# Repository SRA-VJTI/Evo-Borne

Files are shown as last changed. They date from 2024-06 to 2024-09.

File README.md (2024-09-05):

# Evoborne
This repository focuses on building an open-source _morphobot_
Autonomous human-friendly Multi-Terrain Scaling Vehicle

## Table of Contents
- Introduction
- Features
- Use Case

## Introduction
EvoBorne is a versatile multi-terrain modular robot designed to adapt to various surface and aerial environments, morphing its structure to meet the demands of its surroundings. It operates as a wheeled robot on land, navigating diverse terrains with speed and agility, and seamlessly transforms into a drone when flight is required. Equipped with advanced mapping techniques and a dynamic morphing capability, EvoBorne can autonomously switch between ground and aerial modes, optimizing performance for complex tasks such as search and rescue, environmental monitoring, and exploration. Its robust, customizable design makes it a powerful tool for overcoming challenging environments.

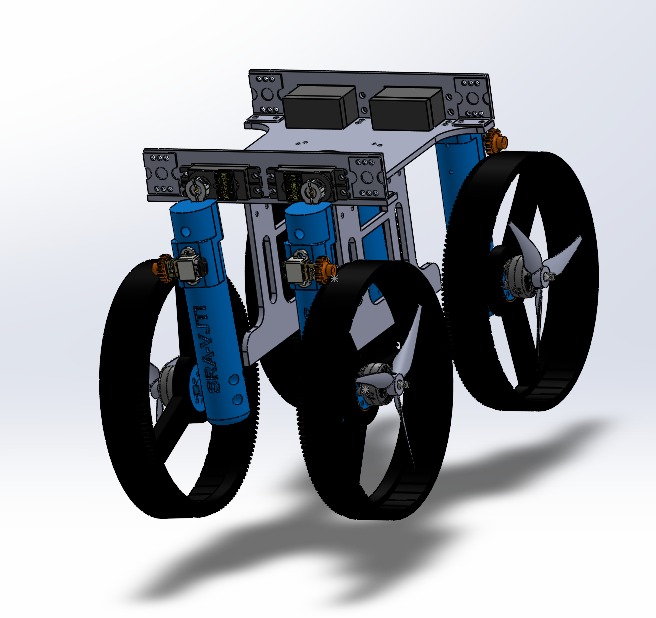
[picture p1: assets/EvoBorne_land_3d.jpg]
EvoBorne chassis


## Features
### Modular & Adaptive Design

EvoBorne's modular design allows it to easily adapt its structure for different environments and tasks. The design is such that it can be reconfigured, enhancing its versatility and enabling quick transitions between ground and aerial modes.

### Powerful Processing Capabilities

EvoBorne is equipped with powerful processors such as the Jetson Nano that can handle real-time navigation. These capabilities allow the robot to execute complex tasks efficiently, supporting advanced terrain mapping and path-finding operations.

### Multiple Operational Modes

EvoBorne can seamlessly switch between multiple operational modes, functioning as a wheeled robot on land and transforming into a drone when aerial mobility is needed. This flexibility allows it to tackle a variety of tasks in diverse environments.

### Efficient Actuation with Custom ESP32 based custom PCB

The robot's actuation system is controlled by a custom ESP32-based development board, providing efficient and precise control over movement and transformations. This tailored setup enhances responsiveness and overall performance.

### Robust & Precise Flight Control

EvoBorne uses a SpeedyBee flight controller for robust and precise flight control, ensuring stable and reliable aerial operations. This system provides advanced control algorithms that enhance the robot's agility and accuracy during flight.

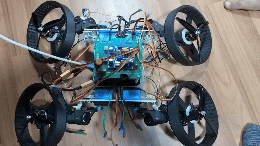
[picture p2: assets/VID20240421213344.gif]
morphing


## Use Case
- EvoBorne is designed to enhance **search and rescue operations** by navigating difficult environments autonomously, using advanced technology to interact with people, and ultimately improving emergency response efficiency. By addressing these issues, EvoBorne could play a vital role in saving lives.
- EvoBorne represents a significant advancement in emergency response technology. Its innovative design and cutting-edge features aim to improve how we handle crises, enabling faster and more efficient assistance in difficult conditions. By reducing the time required to locate and help individuals in danger, EvoBorne could be pivotal in saving lives. Its flexibility and technological sophistication not only make it a valuable tool for rescuers but also push the boundaries of what robots can achieve in real-world scenarios.

## Frameworks & Technologies
- ESP-IDF
- Betaflight
- SolidWorks
- ROS

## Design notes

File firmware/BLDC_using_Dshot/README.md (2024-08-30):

| Supported Targets | ESP32 | ESP32-C3 | ESP32-C6 | ESP32-H2 | ESP32-S2 | ESP32-S3 |
| --- | ----- | --- | --- | --- | --- | --- |
# RMT Infinite Loop Transmit Example -- Dshot ESC (Electronic Speed Controller)

(See the README.md file in the upper level 'examples' directory for more information about examples.)

RMT TX channel can transmit symbols in an infinite loop, where the loop is totally controlled by the hardware. This feature is useful for scenarios where a device needs continuous stimulus.

The [DShot](https://github.com/betaflight/betaflight/wiki/Dshot) is a digital protocol between flight controller (FC) and ESC, which is more resistant to electrical noise than traditional analog protocols. The DShot protocol requires the FC to encode throttle information into pulses with various durations and send out the pulses periodically. This is what an RMT TX channel can perfectly do.

## How to Use Example

### Hardware Required

* A development board with any supported Espressif SOC chip (see `Supported Targets` table above)
* A USB cable for Power supply and programming
* An ESC that supports DShot protocol (this example will take the **DShot300** as an example)

Connection :

```
   BLDC           DShot ESC        12V GND
+--------+     +---------------+    |   |           ESP
|        |     |               |    |   | +----------------------+
|      U +-----+ U          P+ +----+   | |                      |
|        |     |               |        | |                      |
|      V +-----+ V          P- +--------+ |                      |
|        |     |               |          |                      |
|      W +-----+ W         SIG +----------+ DSHOT_ESC_GPIO_NUM   |
|        |     |           GND +----------+ GND                  |
+--------+     +---------------+          +----------------------+
```

The GPIO number used in this example can be changed according to your board, by the macro `DSHOT_ESC_GPIO_NUM` defined in the [source file](main/dshot_esc_example_main.c).

### Build and Flash

Run `idf.py -p PORT flash monitor` to build, flash and monitor the project.

(To exit the serial monitor, type ``Ctrl-]``.)

## Console Output

```
I (0) cpu_start: Starting scheduler on APP CPU.
I (182) example: Create RMT TX channel
I (182) gpio: GPIO[43]| InputEn: 0| OutputEn: 1| OpenDrain: 0| Pullup: 1| Pulldown: 0| Intr:0
I (182) example: Install Dshot ESC encoder
I (182) example: Start RMT TX channel
I (182) example: Start ESC by sending zero throttle for a while...
I (3182) example: Set throttle to 1000, no telemetry
```

The BLDC motor will beep when the ESC receives a burst of initialization pulses. And then starts high-speed rotation at the throttle set in the code.

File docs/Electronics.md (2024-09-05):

---
title: Electronics

---

# Electronics

 - Electronics is a critical part of the EvoBorne robot. All the processing & control applications for the morphobot are performed with the electronics. The electronics for the morphobot has two major components : 
    1. Power Circuitry
    2. Controlling System

## Components used

### **SRA Development Board**
- The [SRA board](https://github.com/SRA-VJTI/sra-board-hardware-design) is our in-house development board based on the ESP32 microcontroller, featuring on-board peripherals such as programmable LEDs, switches, sensor ports for Line Sensor Array and MPU-6050, an over-current and reverse voltage protection circuit, and motor drivers. 
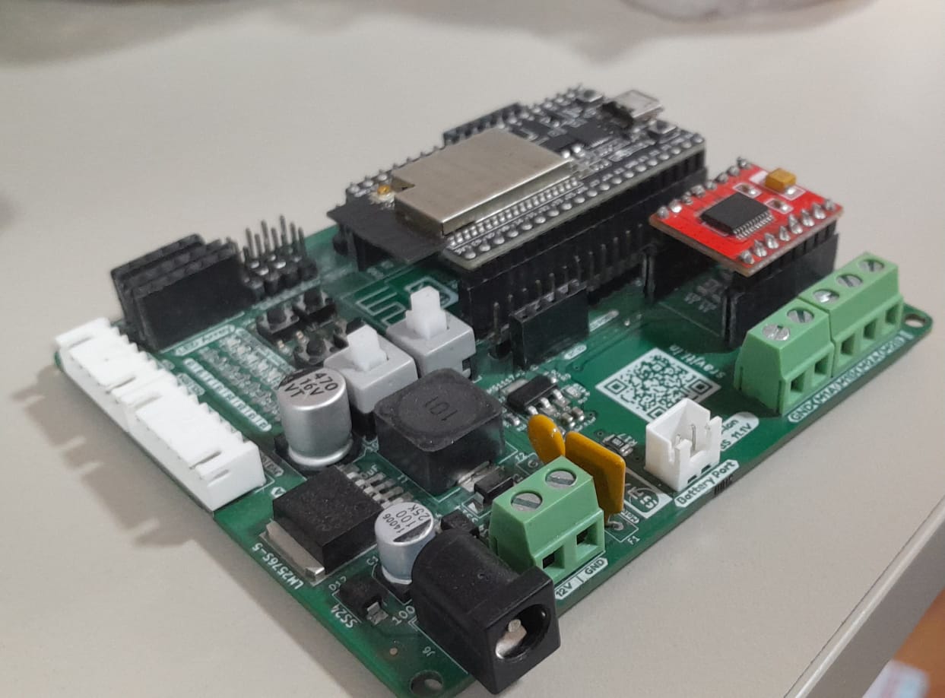
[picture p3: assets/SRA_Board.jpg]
sra-board-24-image
- ![SRA Board v2.5](

- The SRA board is used to connect to & control the servos and the N20 motors through the ESP32. The board has dedicated ports to connect servos as well as normal DC motors. 

### **ESP32-WROOM-32E MCU**
- The ESP32 is primarily being used for controlling the servos and the N20 DC motors for morphing/unmorphing the robot from a wheeled vehicle into a drone. 

### SpeedyBee F405 V3 flight controller
- A flight controller is necessary for controlling the drone effectively. The SpeedyBee F405 V3 has a STM32F405 MCU with an ARM-Cortex M4 core 
- The flight controller’s compact size of 30x30mm makes it compatible with a wide range of frames, from smaller micro quadcopters to larger racing drones. It is based on the popular STM32F405 MCU (Microcontroller Unit) with an ARM Cortex-M4 core, ensuring smooth and efficient processing of data. 
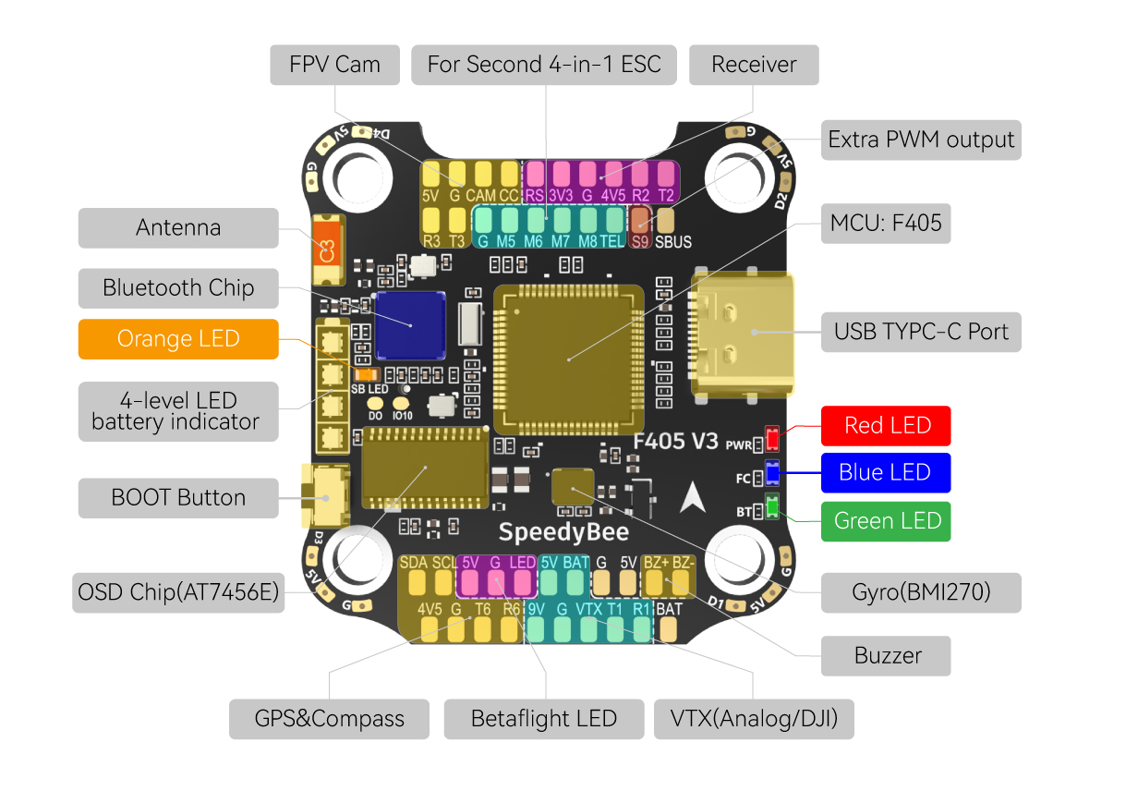
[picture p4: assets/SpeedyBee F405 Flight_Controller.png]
Screenshot from 2024-04-24 10-28-56
 

### Power Circuitry
- The morphobot uses a 24V, 1400 mAh battery to power all of its electronics. Since each component has unique power requirements, an additional circuit is used to manage the input voltage to each component.
- The voltage drop is controlled as required using Buck Converters
- 

### Realsense D435i depth camera
- The Realsense depth camera, specifically the Intel Realsense D435i model, is a stereo vision camera system designed to capture high-resolution depth images. This capability is critical for applications requiring 3D spatial recognition and depth estimation.
- For the morphobot, the Realsense camera provides essential depth information that helps in environment mapping. It allows the morphobot to perceive its surroundings in three dimensions, which is crucial for the drone mode, where understanding the altitude and clearance around obstacles directly influences flight safety and stability.
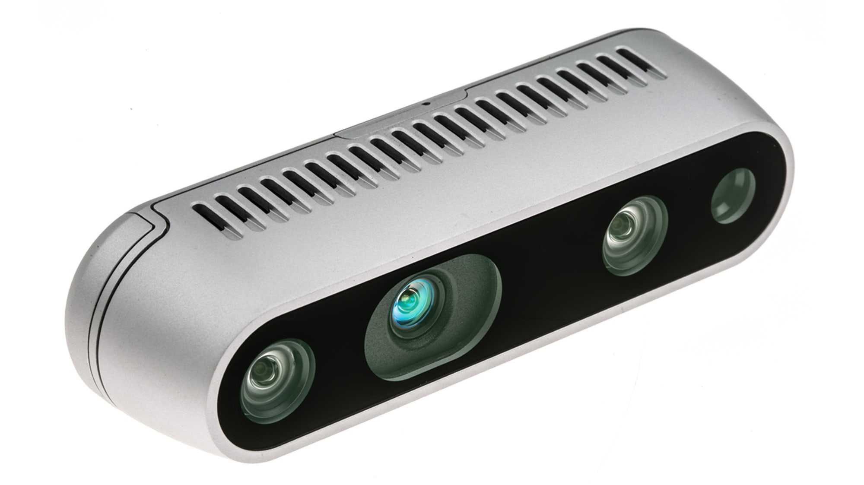
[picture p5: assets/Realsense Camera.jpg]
realsense d435i img
 

- The camera features a wide field of view and can generate depth data at a high frame rate, which is beneficial for the dynamic environments in which the morphobot operates. The integration of this camera enhances the morphobot's ability to interact intelligently with its environment, contributing significantly to its autonomous capabilities.

### Jetson Nano Developer Kit
- The Jetson Nano Developer Kit from NVIDIA is a small, powerful computer designed specifically for learning and development of robotics projects. It is based on the NVIDIA Jetson Nano SoC, which combines a quad-core ARM Cortex-A57 MPCore processor and a 128-core Maxwell GPU. This combination makes it highly effective for tasks,such as image processing & deep learning.
    
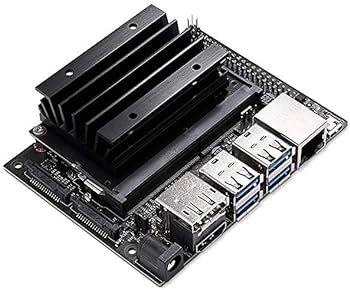
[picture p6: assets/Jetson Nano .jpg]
jetson_nano


- In the context of the morphobot, the Jetson Nano Developer Kit is utilized for high-level processing tasks such as image and video analysis, obstacle detection, and navigation intelligence. Its powerful processing capabilities enable the morphobot to perform complex computations required for autonomous decision-making and environment interaction, particularly in scenarios where rapid response to sensor inputs is crucial.

### 4-in-1 ESC
- Electronic Speed Controllers (ESC's) are integral to controlling the power supplied to the motors of drones. A 4-in-1 ESC consolidates four individual ESCs into one compact module, which simplifies the wiring and reduces the overall weight and complexity of the drone assembly in the morphobot.
- Each of the integrated ESCs can independently manage one of the drone's brushless BLDC motors, providing precise control over the speed and direction of each motor which is crucial for maintaining stability and maneuverability during the drone's flight.
4-in1 esc kit

    The use of a 4-in-1 ESC not only optimizes the electrical efficiency but also improves the reliability and responsiveness of the drone system, which are vital characteristics during both flight and morphing transitions.

Overall, the morphobot's electronics system is a coordinated assembly of different components that work together to deliver impressive capabilities in both its drone and wheeled configurations. From power management and motor control to high-level  depth perception, each component plays an important role in ensuring the morphobot's functionality and performance across various operational scenarios.

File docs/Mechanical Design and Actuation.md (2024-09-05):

---
title: Mechanical Design and Actuation

---

# Mechanical Design and Actuation

Mechanical design is an essential stage in the development of any robot. The robot's future prospects are influenced by how it is designed. 

##  Mechanical Design

__Modular Design__: The EvoBorne's chassis is built of lightweight yet robust components like aluminium and 3D printed PLA parts. The EvoBorne's mainframe is made of aluminium that houses the electronics assembly. The arms and wheels are 3D printed and attached through the servos mounted on the mainframe. 

This modular design facilitates part replacement and maintenance, as well as adaptability to varied configurations for specialized applications or situations.

__Frame and Structure:__

Designing the morphobot was a major task ; as it was to be tailor-made to perform in multiple modes ( aerial & terrestrial ). It was designed keeping in mind the following factors :
1. Terrestrial motion : When traversing on land , the EvoBorne needs to be stable enough to continue smooth motion at moderate velocity on diverse terrain. That meant ensuring the chassis was perfectly balanced in terms of size & weight . Also ,the morphing process was also to be considered;it should be able to morph & unmorph efficiently without any damage to itself or the surroundings. The wheels needed to be large enough to encase the propellers but small enough to maintain a stable COM. 
morphobot_quad_mode

2. Flight : Flying the EvoBorne was the most critical point while designing the EvoBorne . Even a slight discrepancy in the geometry could affect its flying capabilities fatally. The thrust-to-weight ratio was also taken into consideration while designing the frame. It has a H-airframe 
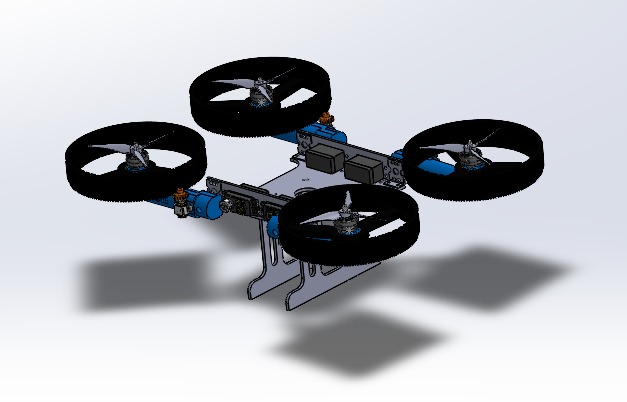
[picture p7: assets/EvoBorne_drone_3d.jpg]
morphobot_drone_mode


### Actuation

Wheel and Drone Components:

Wheels and Motors: For ground mobility, the morphobot is equipped with small, powerful brushless DC motors, possibly the N20 motor type, known for their compact size and high torque output. The wheels are designed to be lightweight with a durable tread capable of handling different terrains.
    Propellers and ESCs: In drone mode, the propellers are deployed. These are driven by brushless motors controlled by 4-in-1 ESCs (Electronic Speed Controllers), which manage the speed and direction of each motor to control flight dynamics such as lift, pitch, roll, and yaw.

Actuation and Transition:

- Servo Motors: 
    - Servo motors are critical for the transformation process, providing precise control over the transition process to switch between the EvoBorne's two forms. They must be robust enough to handle the mechanical stress from the thrust when in drone mode and responsive enough to ensure a smooth transition. 
    - We have used OT5325 servo motors for the EvoBorne that provide a stall torque of 25 kg-cm when operating at 7.4V ; this is essential to ensure that the arms of the EvoBorne do not tilt due to thrust from the propellers. 
- N20 motors:
    - The EvoBorne utilizes these motors to perform terrestrial motion. These motors are connected to the wheel through a spur gear system ; one gear on the shaft and the other on the wheel's circumference. This system is a high-torque,low-speed system that will provide better traction on all surfaces.
- Brushless BLDC motors :
    - The EvoBorne uses Emax ECOII-2807-1700KV BLDC motors for flight . These motors have a 1700 Kv (rpm/volt) rating and are controlled via the 4-in-1 ESC. It uses 6' propellers 

- Locking Mechanisms: Reliable locking mechanisms are essential to ensure stability in both modes. These might include magnetic locks or mechanical latches that secure moving parts once the transformation is complete.

Stability and Maneuverability:

In summary, the mechanical design of the morphobot is a sophisticated blend of robotics engineering, combining elements from both aerial and terrestrial technologies to create a versatile and dynamic machine capable of operating in diverse environments and fulfilling a range of tasks. This design not only challenges existing engineering practices but also pushes the boundaries of what is technically feasible in robotic transformations.

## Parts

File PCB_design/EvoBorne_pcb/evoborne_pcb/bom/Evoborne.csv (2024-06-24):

Reference | Value | Datasheet | Footprint | Qty
C1,C24,C25 | 10uF | ~ | Capacitor_SMD:C_0603_1608Metric | 3
C2,C4,C22,C33 | 0.1uF | ~ | Capacitor_SMD:C_0603_1608Metric | 4
C3 | 22uF | ~ | Capacitor_SMD:C_0603_1608Metric | 1
C5,C9,C12 | 220uF | ~ | Capacitor_SMD:CP_Elec_6.3x7.7 | 3
C6,C7,C8,C10,C13,C14,C15,C17,C18,C26 | 1uF | ~ | Capacitor_SMD:C_0603_1608Metric | 10
C11,C16,C19 | 330uF | ~ | Capacitor_SMD:CP_Elec_8x10.5 | 3
C20,C21 | 22 pF | ~ | Capacitor_SMD:C_0603_1608Metric | 2
D1,D3 | SS34 | http://www.vishay.com/docs/88526/1n5820.pdf | Diode_SMD:D_SMB | 2
D2,D5,D9,D10,D11,D12,D13,D14,D15,D16,D17,D18,D19,D20 | LED | ~ | LED_SMD:LED_0603_1608Metric | 14
D4,D6,D7 | B540 |  | Diode_SMD:Diode B540 | 3
D8 | SS54 | http://www.vishay.com/docs/88526/1n5820.pdf | Diode_SMD:D_SMA | 1
F1 | 3A | ~ | Fuse:RUEF160 | 1
F2 | 5A | ~ | Fuse:5A PTC Fuse RGEF500 | 1
F3 | 300mA | ~ | PTC Fuse:1A PTC Fuse RXEF050 | 1
H1,H2,H3,H4 | MountingHole | ~ | MountingHole:MountingHole_3.2mm_M3 | 4
J1,J2,J3,J4 | B2B-XH-A_LF__SN_ |  | Connector:2 Pin JST | 4
J5,J6,J7,J8 | Conn_01x03_Pin | ~ | Header Pins:Headers 1X03 | 4
J9,J10 | XT60 |  | 2 Male 90 Headers | 2
J11,J12,J15 | Conn_01x08_Male | ~ | Connector_PinHeader_2.54mm:PinHeader_1x08_P2.54mm_Vertical | 3
J13 | Screw_Terminal_01x02 | ~ | TerminalBlock:TerminalBlock_bornier-2_P5.08mm | 1
J14 | USB_C_Receptacle_USB2.0 | https://www.usb.org/sites/default/files/documents/usb_type-c.zip | Connector_USB:USB_C_Receptacle_G-Switch_GT-USB-7010ASV | 1
J16,J17 | Conn_01x14_Pin | ~ | Connector_PinHeader_2.54mm:PinHeader_1x14_P2.54mm_Vertical | 2
J18,J19 | Conn_01x02_Pin | ~ | Connector_PinHeader_2.54mm:PinHeader_1x02_P2.54mm_Vertical | 2
L1,L2,L3 | 47uH | ~ | Inductor_SMD:L_10.4x10.4_H4.8 | 3
Q1,Q2 | SS8050 | https://www.fairchildsemi.com/datasheets/2N/2N3904.pdf | Package_TO_SOT_SMD:SOT-23 | 2
R1,R2,R3,R4 | 1k |  | Resistor_SMD:R_1206_3216Metric | 4
R19 | 1k | ~ | Resistor_SMD:R_0603_1608Metric | 1
R5,R6,R7 | TrimPOT 3296 |  | Potentiometer_THT:TrimPOT_3296 | 3
R8,R9,R27,R11,R12,R13,R14,R15,R16,R17,R18,R20 | 330 | ~ | Resistor_SMD:R_0603_1608Metric | 12
R10 | 100k | ~ | Resistor_SMD:R_0805_2012Metric | 1
R21 | 2k | ~ | Resistor_SMD:R_0603_1608Metric | 1
R22 | 3.3k | ~ | Resistor_SMD:R_0805_2012Metric | 1
R23,R24 | 6.8k | ~ | Resistor_SMD:R_0805_2012Metric | 2
R25,R26,R28,R29 | 5.1 k | ~ | Resistor_SMD:R_0402_1005Metric | 4
SW1 | High Current 3 Pin spdt Switch |  | Switches:3pin High Current SPDT Switch | 1
SW2 | SW_N20 | ~ | Switches:6 Pin THT Push Switch | 1
SW3 | SW_Servos | ~ | Switches:6 Pin THT Push Switch | 1
SW4 | SW_Jetson | ~ | Switches:6 Pin THT Push Switch | 1
SW5 | EN | ~ | Button_Switch_SMD:SW_Push_SPST_NO_Alps_SKRK | 1
SW6 | BOOT | ~ | Button_Switch_SMD:SW_Push_SPST_NO_Alps_SKRK | 1
SW7,SW8 | SW_Push_Dual | ~ | Switches:Tactile Smd 2x2 | 2
U1 | TB6612FNG |  | Motor driver:TB6612FNG | 1
U2 | AMS1117-3.3 | http://www.advanced-monolithic.com/pdf/ds1117.pdf | Package_TO_SOT_SMD:SOT-223-3_TabPin2 | 1
U3 | ESP32-WROOM Chip |  | RF_Module:ESP32-WROOM-32E__4MB_HIGH_TEMP_CHIP | 1
U4,U5,U6 | XL4015 | http://www.xlsemi.net/datasheet/XL4015%20datasheet-English.pdf | Package_TO_SOT_SMD:TO-263-5_TabPin3 | 3
U7 | CH340G | http://www.datasheet5.com/pdf-local-2195953 | Package_SO:SOIC-16_3.9x9.9mm_P1.27mm | 1
Y1 | 12MHz | ~ | Crystal:Crystal_SMD_3225-4Pin_3.2x2.5mm | 1

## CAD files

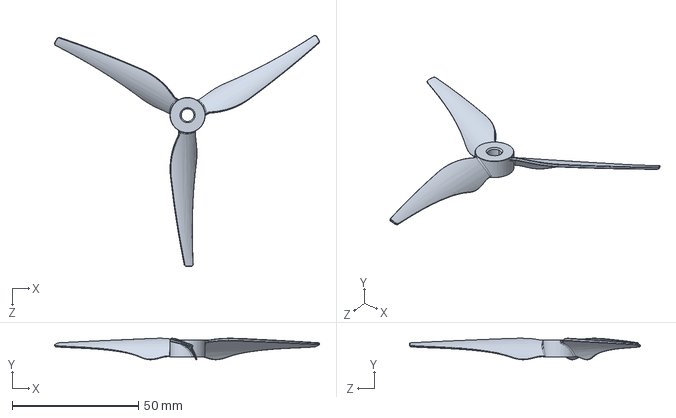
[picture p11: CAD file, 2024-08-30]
CAD_designs/gemfan propeller 51466.SLDPRT
105.0 x 8.54 x 91.6 mm

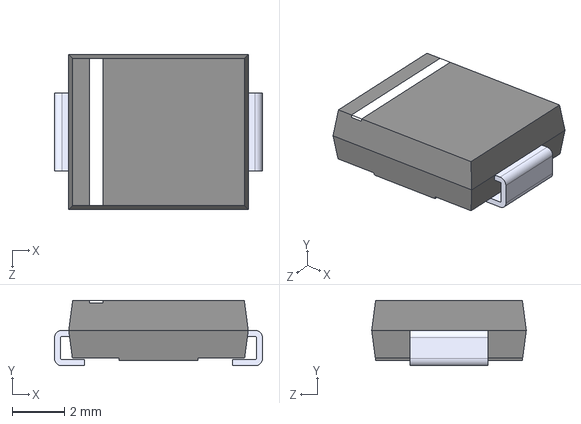
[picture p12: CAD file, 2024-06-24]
PCB_design/EvoBorne_pcb/evoborne_pcb/components_libraries/B540/B540C-13-F.step
7.94 x 2.50 x 5.91 mm

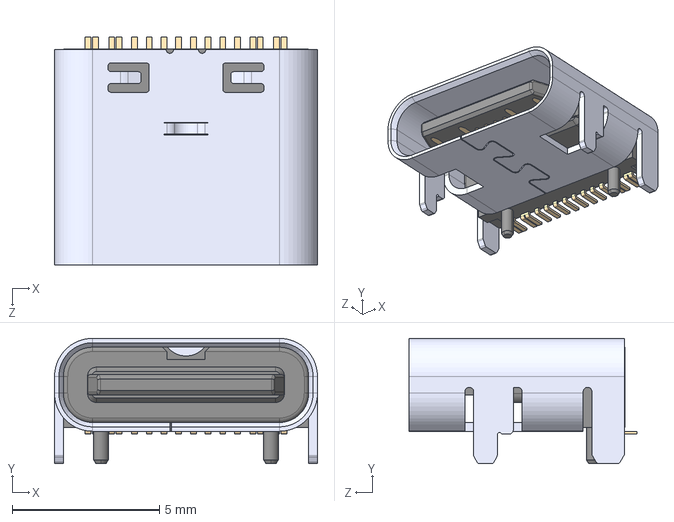
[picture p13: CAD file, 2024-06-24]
PCB_design/EvoBorne_pcb/evoborne_pcb/components_libraries/Connectors/USB C/CSP-USC16-TR.step
8.94 x 4.26 x 7.75 mm

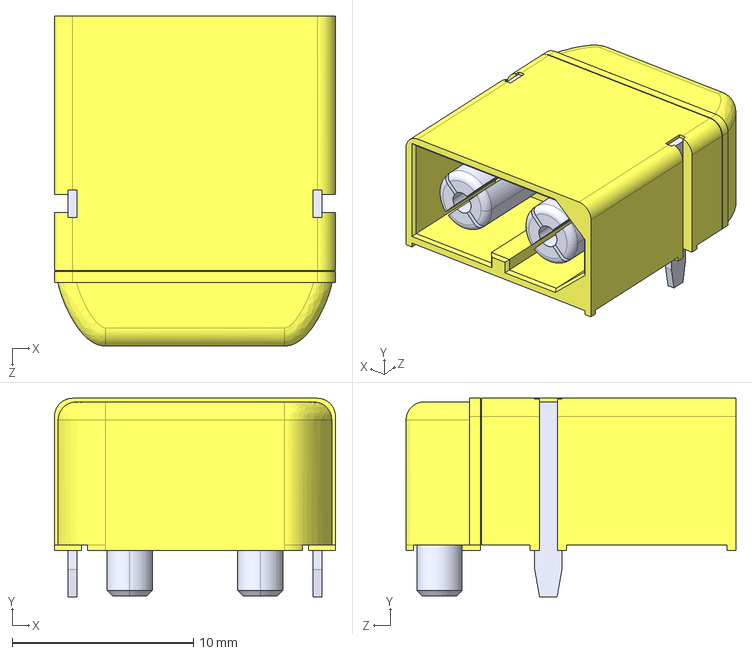
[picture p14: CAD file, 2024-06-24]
PCB_design/EvoBorne_pcb/evoborne_pcb/components_libraries/Connectors/XT 60/XT60PW-M.step
15.5 x 11.0 x 18.2 mm

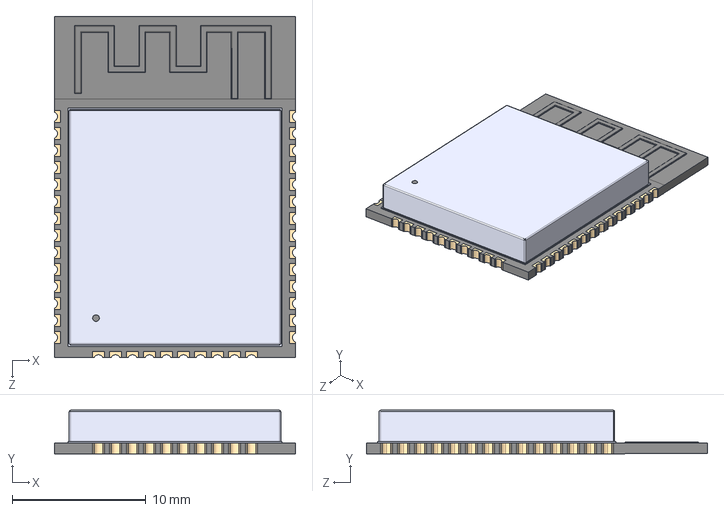
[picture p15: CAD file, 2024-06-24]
PCB_design/EvoBorne_pcb/evoborne_pcb/components_libraries/ESP32-WROOM/ESP32-WROOM-32E__4MB_HIGH_TEMP_.step
18.0 x 3.25 x 25.5 mm

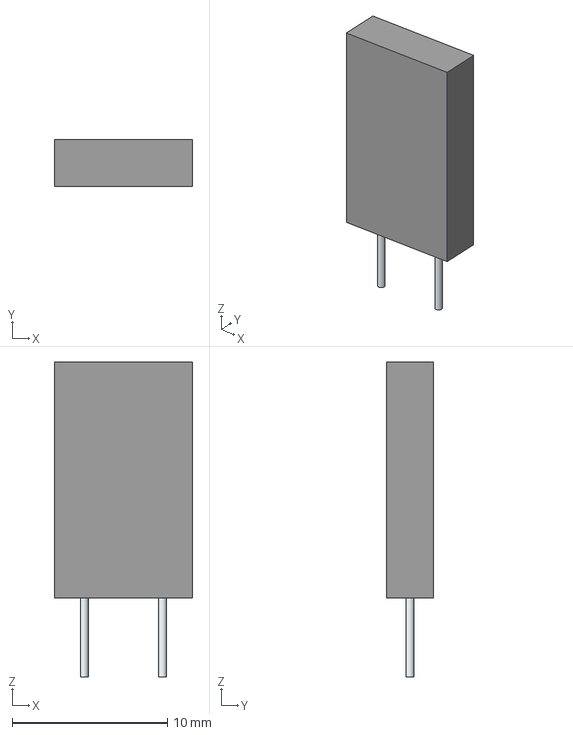
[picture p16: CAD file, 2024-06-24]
PCB_design/EvoBorne_pcb/evoborne_pcb/components_libraries/Fuse/3A PTC Fuse RUEF160/RUEF160.stp
8.90 x 3.00 x 20.3 mm
Leads

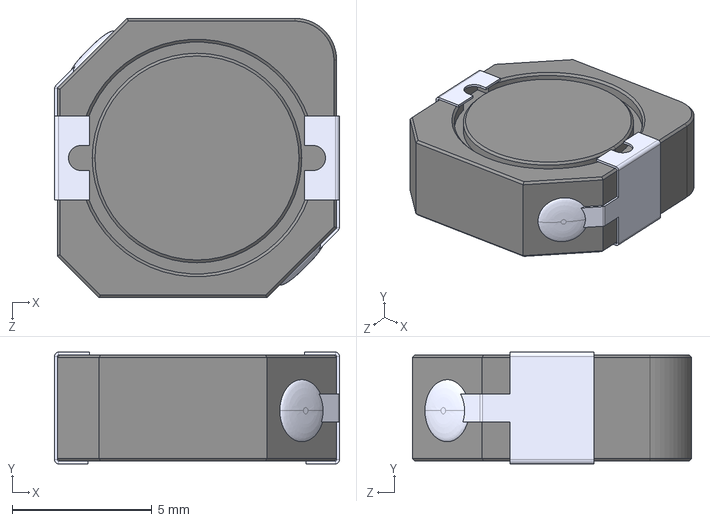
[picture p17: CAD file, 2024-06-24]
PCB_design/EvoBorne_pcb/evoborne_pcb/components_libraries/Inductor/47uH Inductor.STEP
10.2 x 4.00 x 10.0 mm

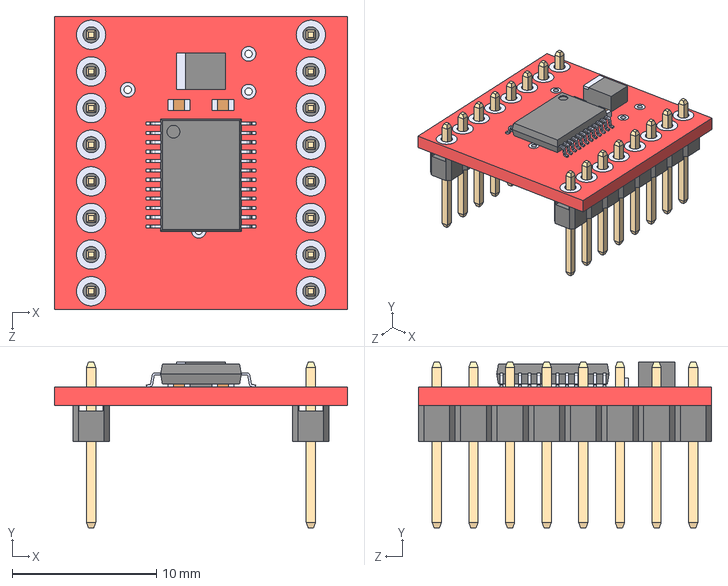
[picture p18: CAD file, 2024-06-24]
PCB_design/EvoBorne_pcb/evoborne_pcb/components_libraries/Motor Driver/ROB-14450.step
20.3 x 11.5 x 20.3 mm

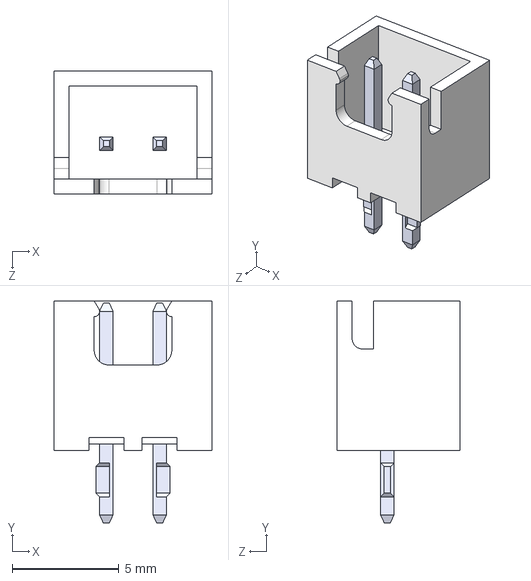
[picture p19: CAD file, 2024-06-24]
PCB_design/EvoBorne_pcb/evoborne_pcb/components_libraries/Motor JST Connector/B2B-XH-A_LF__SN_.step
7.40 x 10.4 x 5.75 mm

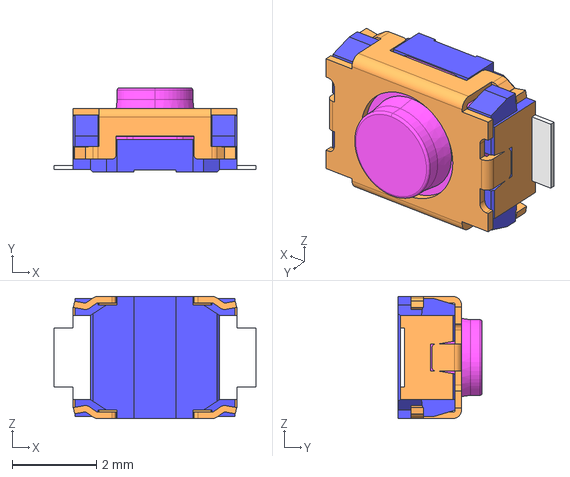
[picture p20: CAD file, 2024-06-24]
PCB_design/EvoBorne_pcb/evoborne_pcb/components_libraries/Switch/Esp-32 Switch/skrkaee010.stp
4.80 x 2.00 x 2.90 mm

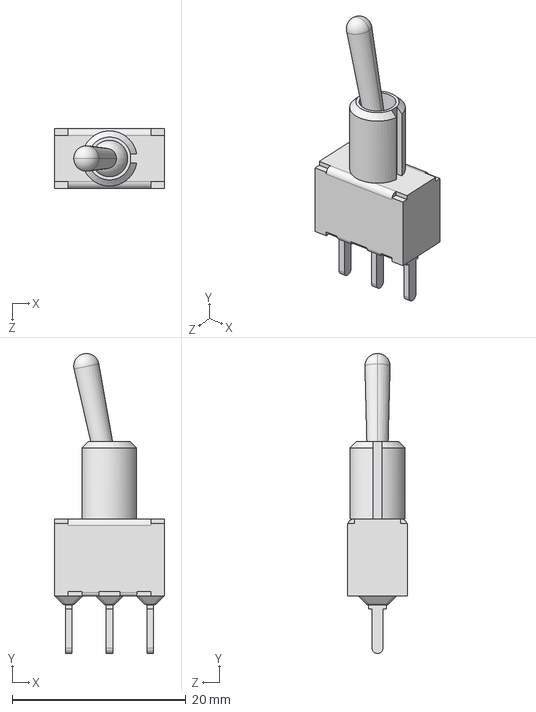
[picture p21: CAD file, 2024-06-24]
PCB_design/EvoBorne_pcb/evoborne_pcb/components_libraries/Switch/High Current 3 Pin spdt Switch/100SP3T1B1M2QEH.step
12.7 x 34.5 x 6.86 mm

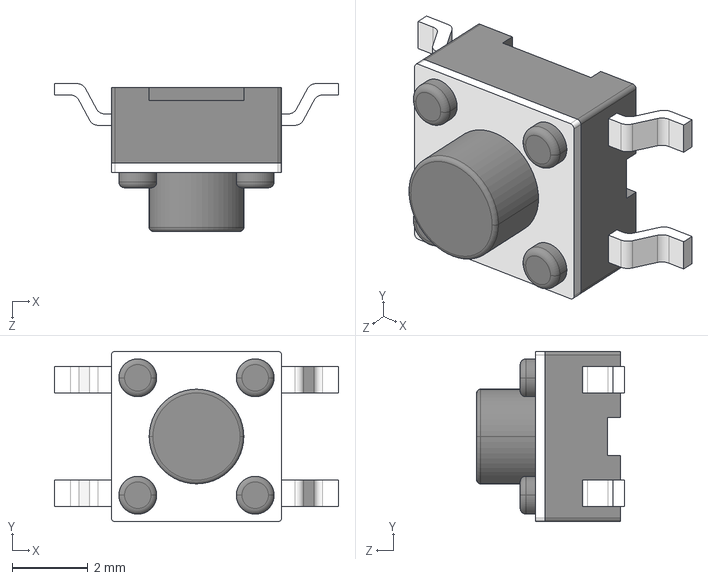
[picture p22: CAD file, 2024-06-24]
PCB_design/EvoBorne_pcb/evoborne_pcb/components_libraries/Switch/tactile_smd/spst_tactile_sw_2x02_smd.stp
7.50 x 4.50 x 3.90 mm

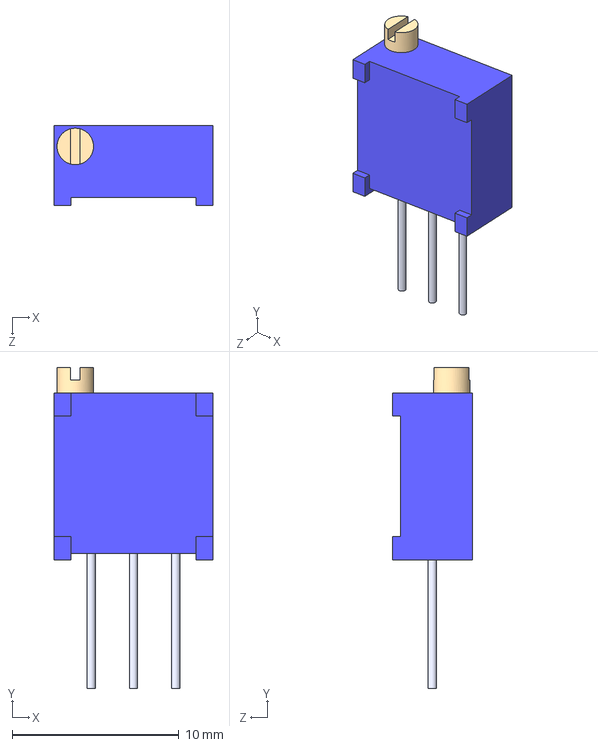
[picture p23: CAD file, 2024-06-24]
PCB_design/EvoBorne_pcb/evoborne_pcb/components_libraries/TrimPOT 3296/3296W-1-250.step
9.53 x 19.3 x 4.83 mm

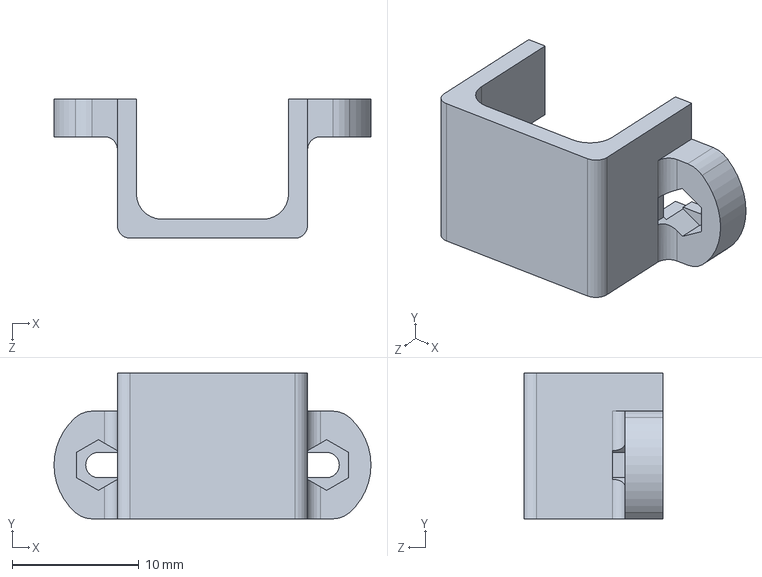
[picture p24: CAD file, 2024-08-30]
CAD_designs/N20-Bracket.SLDPRT
25.0 x 11.5 x 11.0 mm

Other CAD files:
PCB_design/EvoBorne_pcb/evoborne_pcb/components_libraries/Switch/dpdt_tht/dpdt_sw_2x03_tht.STEP
CAD_designs/stand.SLDPRT
CAD_designs/Right_leg_final.SLDPRT
CAD_designs/Bearing_Proto.SLDPRT
CAD_designs/Chassis2.SLDPRT
CAD_designs/Left_leg_final.SLDPRT
CAD_designs/Mg995.SLDPRT
CAD_designs/Motor_HOLDER2.O.SLDPRT
CAD_designs/N20 DC MOTOR.SLDPRT
CAD_designs/N20-Gear.SLDPRT
CAD_designs/SERVO ARM HORN 25T ALUMINIUM.step.SLDPRT
CAD_designs/Wheel_morpho.SLDPRT
PCB_design/EvoBorne_pcb/evoborne_pcb/components_libraries/Fuse/3A PTC Fuse RUEF160/RUEF160.stl
PCB_design/EvoBorne_pcb/evoborne_pcb/components_libraries/Switch/dpdt_tht/dpdt_sw_2x03_tht - Copy.STEP

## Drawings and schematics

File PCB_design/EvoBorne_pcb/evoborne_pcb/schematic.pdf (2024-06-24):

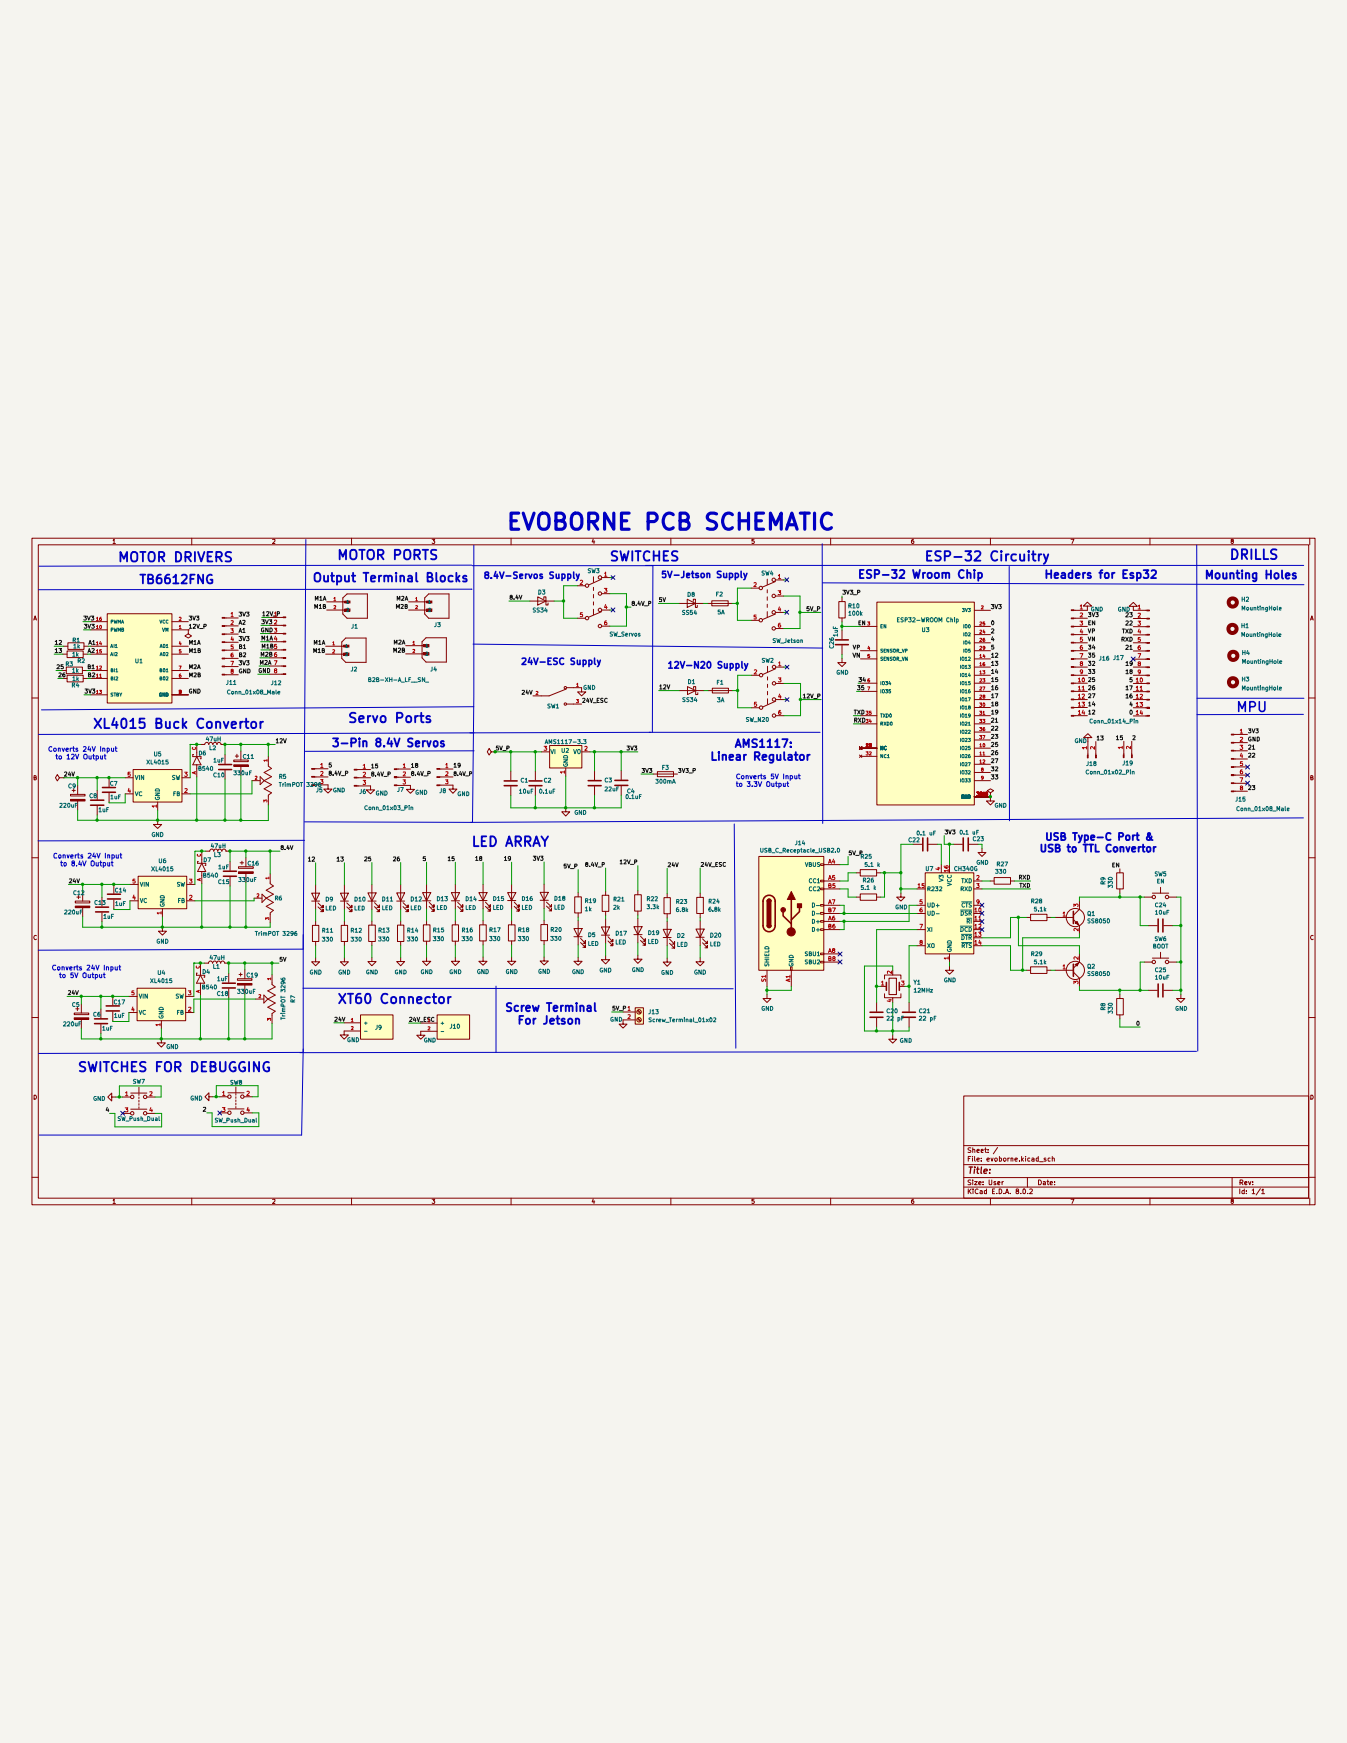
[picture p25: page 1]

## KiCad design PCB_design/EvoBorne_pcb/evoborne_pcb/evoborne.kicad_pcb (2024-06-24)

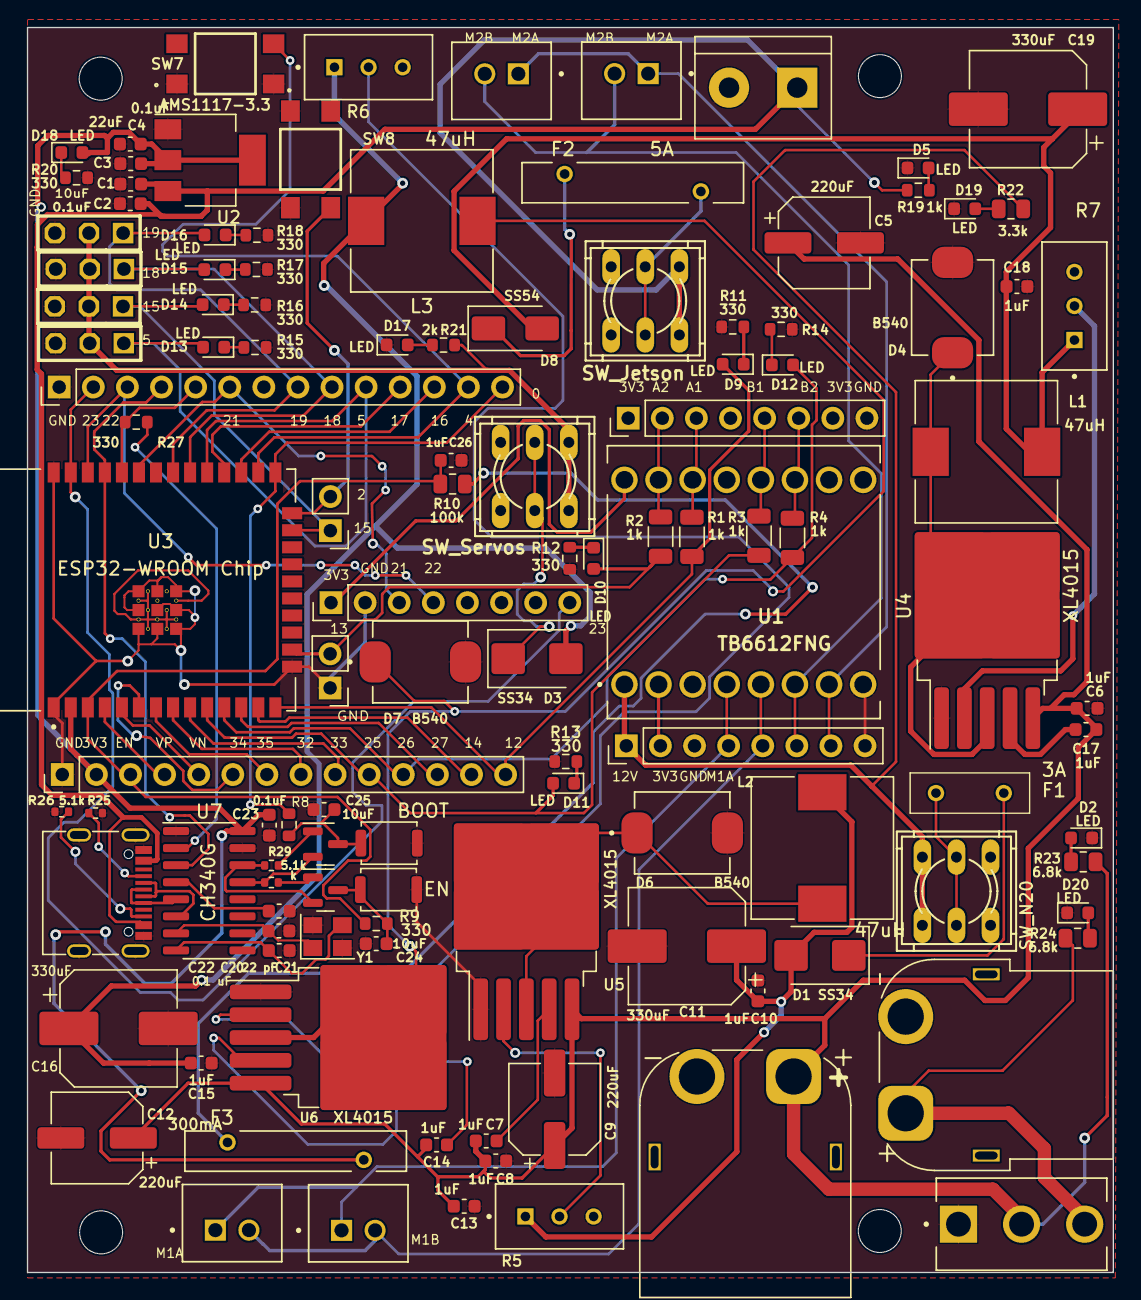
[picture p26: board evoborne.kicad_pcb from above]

Board: 2 copper layers, 80.9 x 92.7 mm, 122 parts (0 on the bottom side), 88 nets.

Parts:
C1, C24, C25: 10uF; C_0603_1608Metric
C2, C4, C23: 0.1uF; C_0603_1608Metric
C3: 22uF; C_0603_1608Metric
C5, C9, C12: 220uF; CP_Elec_6.3x7.7
C6, C7, C8, C10, C13, C14, C15, C17, C18, C26: 1uF; C_0603_1608Metric
C11, C16, C19: 330uF; CP_Elec_8x10.5
C20, C21: 22 pF; C_0603_1608Metric
C22: 0.1 uF; C_0603_1608Metric
D1, D3: SS34; D_SMB
D2, D5, D9, D10, D11, D12, D13, D14, D15, D16, D17, D18, D19, D20: LED; LED_0603_1608Metric
D4, D6, D7: B540; Diode B540
D8: SS54; D_SMA
F1: 3A; RUEF160
F2: 5A; 5A PTC Fuse RGEF500
F3: 300mA; 1A PTC Fuse RXEF050
H1, H2, H3, H4: MountingHole; MountingHole_3.2mm_M3
J1, J2, J3, J4: B2B-XH-A_LF__SN_; 2 Pin JST
J5, J6, J7, J8: Conn_01x03_Pin; Headers 1X03
J9: XT60; AMASS_XT60PW-M_1x02_P7.20mm_Horizontal
J10: XT60; AMASS_XT60PW-F_1x02_P7.20mm_Horizontal
J11, J12, J15: Conn_01x08_Male; PinHeader_1x08_P2.54mm_Vertical
J13: Screw_Terminal_01x02; TerminalBlock_bornier-2_P5.08mm
J14: USB_C_Receptacle_USB2.0; USB_C_Receptacle_G-Switch_GT-USB-7010ASV
J16, J17: Conn_01x14_Pin; PinHeader_1x14_P2.54mm_Vertical
J18, J19: Conn_01x02_Pin; PinHeader_1x02_P2.54mm_Vertical
L1, L2, L3: 47uH; L_10.4x10.4_H4.8
Q1, Q2: SS8050; SOT-23
R1, R2, R3, R4: 1k; R_1206_3216Metric
R5, R6, R7: TrimPOT 3296; TrimPOT_3296
R8, R9, R11, R12, R13, R14, R15, R16, R17, R18, R20, R27: 330; R_0603_1608Metric
R10: 100k; R_0805_2012Metric
R19: 1k; R_0603_1608Metric
R21: 2k; R_0603_1608Metric
R22: 3.3k; R_0805_2012Metric
R23, R24: 6.8k; R_0805_2012Metric
R25: 5.1 k; R_0402_1005Metric
R26, R28, R29: 5.1k; R_0402_1005Metric
SW1: High Current 3 Pin spdt Switch; 3pin High Current SPDT Switch
SW2: SW_N20; 6 Pin THT Push Switch
SW3: SW_Servos; 6 Pin THT Push Switch
SW4: SW_Jetson; 6 Pin THT Push Switch
SW5: EN; SW_Push_SPST_NO_Alps_SKRK
SW6: BOOT; SW_Push_SPST_NO_Alps_SKRK
SW7, SW8: SW_Push_Dual; Tactile Smd 2x2
U1: TB6612FNG
U2: AMS1117-3.3; SOT-223-3_TabPin2
U3: ESP32-WROOM Chip; ESP32-WROOM-32E__4MB_HIGH_TEMP_CHIP
U4, U5, U6: XL4015; TO-263-5_TabPin3
U7: CH340G; SOIC-16_3.9x9.9mm_P1.27mm
Y1: 12MHz; Crystal_SMD_3225-4Pin_3.2x2.5mm

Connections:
/0: J17.14, R8.2, U3.25 (IO0)
/2: J19.2, SW8.4, U3.24 (IO2)
/3V3: C3.1, C4.1, C23.2, D18.2 (A), F3.1, J11.1, J11.4, J11.7, J12.2, J15.1, J16.2, U1.2 (VCC), U1.10 (PWMB), U1.13 (STBY), U1.16 (PWMA), U2.2 (VO), U3.2 (3V3), U7.16 (VCC)
/3V3_P: F3.2, R10.2
/4: J17.13, SW7.4, U3.26 (IO4)
/5: D13.2 (A), J5.1, J17.10, U3.29 (IO5)
/5V: C18.1, C19.1, D8.2 (A), L1.2, R7.1
/5V_P: C1.1, C2.1, J13.1, J14.A4 (VBUS), J14.A9 (VBUS), J14.B4 (VBUS), J14.B9 (VBUS), R19.1, SW4.3 (C), SW4.6 (C), U2.3 (VI)
/8.4V: C15.1, C16.1, D3.2 (A), L3.2, R6.1
/8.4V_P: J5.2, J6.2, J7.2, J8.2, R21.1, SW3.3 (C), SW3.6 (C)
/12: D9.2 (A), J16.14, R1.1, U3.14 (IO12)
/12V: C10.1, C11.1, D1.2 (A), L2.2, R5.1
/12V_P: J12.1, R22.1, SW2.3 (C), SW2.6 (C), U1.1 (VM)
/13: D10.2 (A), J18.2, R2.1, U3.16 (IO13)
/14: J16.13, U3.13 (IO14)
/15: D14.2 (A), J6.1, J19.1, U3.23 (IO15)
/16: J17.12, U3.27 (IO16)
/17: J17.11, U3.28 (IO17)
/18: D15.2 (A), J7.1, J17.9, U3.30 (IO18)
/19: D16.2 (A), J8.1, J17.8, U3.31 (IO19)
/21: J15.3, J17.6, U3.33 (IO21)
/22: J15.4, J17.3, U3.36 (IO22)
/23: J15.8, J17.2, U3.37 (IO23)
/24V: C5.1, C6.1, C7.1, C8.1, C9.1, C12.1, C13.1, C14.1, C17.1, J9.1 (+), R23.1, SW1.2, U4.5 (VIN), U5.5 (VIN), U6.5 (VIN)
/24V_ESC: J10.1 (+), R24.1, SW1.3
/25: D11.2 (A), J16.10, R3.1, U3.10 (IO25)
/26: D12.2 (A), J16.11, R4.1, U3.11 (IO26)
/27: J16.12, U3.12 (IO27)
/32: J16.8, U3.8 (IO32)
/33: J16.9, U3.9 (IO33)
/34: J16.6, U3.6 (IO34)
/35: J16.7, U3.7 (IO35)
/A1: J11.3, R1.2, U1.14 (AI1)
/A2: J11.2, R2.2, U1.15 (AI2)
/B1: J11.5, R3.2, U1.12 (BI1)
/B2: J11.6, R4.2, U1.11 (BI2)
/EN: C26.1, J16.3, R9.1, R10.1, U3.3 (EN)
/M1A: J1.1, J2.1, J12.4, U1.4 (A01)
/M1B: J1.2, J2.2, J12.5, U1.5 (A02)
/M2A: J3.1, J4.1, J12.7, U1.7 (B01)
/M2B: J3.2, J4.2, J12.6, U1.6 (B02)
/RXD: J17.5, R27.1, U3.34 (RXD0)
/TXD: J17.4, U3.35 (TXD0), U7.3 (RXD)
/VN: J16.5, U3.5 (SENSOR_VN)
/VP: J16.4, U3.4 (SENSOR_VP)
GND: C1.2, C2.2, C3.2, C4.2, C5.2, C6.2, C8.2, C9.2, C10.2, C11.2, C12.2, C13.2, C15.2, C16.2, C18.2, C19.2, C20.2, C21.2, C22.2, C23.1, C24.1, C25.1, C26.2, D2.1 (K), D4.A, D5.1 (K), D6.A, D7.A, D17.1 (K), D19.1 (K), D20.1 (K), J5.3, J6.3, J7.3, J8.3, J9.2 (-), J10.2 (-), J11.8, J12.3, J12.8, J13.2, J14.A1 (GND), J14.A12 (GND), J14.B1 (GND), J14.B12 (GND), J14.S1 (SHIELD), J15.2, J16.1, J17.1, J18.1, R5.3, R6.3, R7.3, R11.2, R12.2, R13.2, R14.2, R15.2, R16.2, R17.2, R18.2, R20.2, R25.2, R26.1, SW1.1, SW5.2, SW6.2, SW7.1, SW7.2, SW8.1, SW8.2, U1.3 (GND), U1.8 (GND), U1.9 (GND), U2.1 (GND), U3.1 (GND), U3.15 (GND), U3.38 (GND), U3.39_1 (GND), U3.39_2 (GND), U3.39_3 (GND), U3.39_4 (GND), U3.39_5 (GND), U3.39_6 (GND), U3.39_7 (GND), U3.39_8 (GND), U3.39_9 (GND), U4.1 (GND), U5.1 (GND), U6.1 (GND), U7.1 (GND), U7.15 (R232), Y1.2, Y1.4
unnamed: D1.1 (K), F1.1
unnamed: D2.2 (A), R23.2
unnamed: D3.1 (K), SW3.2 (B), SW3.5 (B)
unnamed: D5.2 (A), R19.2
unnamed: D8.1 (K), F2.1
unnamed: D9.1 (K), R11.1
unnamed: D10.1 (K), R12.1
unnamed: D11.1 (K), R13.1
unnamed: D12.1 (K), R14.1
unnamed: D13.1 (K), R15.1
unnamed: D14.1 (K), R16.1
unnamed: D15.1 (K), R17.1
unnamed: D16.1 (K), R18.1
unnamed: D17.2 (A), R21.2
unnamed: D18.1 (K), R20.1
unnamed: D19.2 (A), R22.2
unnamed: D20.2 (A), R24.2
unnamed: F1.2, SW2.2 (B), SW2.5 (B)
unnamed: F2.2, SW4.2 (B), SW4.5 (B)
unnamed: J14.A5 (CC1), R25.1
unnamed: J14.B5 (CC2), R26.2
unnamed: Q1.1 (B), R28.1
unnamed: C24.2, Q1.3 (C), R9.2, SW5.1
unnamed: Q1.2 (E), R29.2, U7.14 (~RTS)
unnamed: Q2.1 (B), R29.1
unnamed: C25.2, Q2.3 (C), R8.1, SW6.1
unnamed: Q2.2 (E), R28.2, U7.13 (~DTR)
unnamed: R7.2, U4.2 (FB)
unnamed: D4.C, L1.1, U4.3 (SW)
unnamed: C17.2, U4.4 (VC)
unnamed: R5.2, U5.2 (FB)
unnamed: D6.C, L2.1, U5.3 (SW)
unnamed: C7.2, U5.4 (VC)
unnamed: R6.2, U6.2 (FB)
unnamed: D7.C, L3.1, U6.3 (SW)
unnamed: C14.2, U6.4 (VC)
unnamed: R27.2, U7.2 (TXD)
unnamed: J14.A6 (D+), J14.B6 (D+), U7.5 (UD+)
unnamed: J14.A7 (D-), J14.B7 (D-), U7.6 (UD-)
unnamed: C22.1, U7.4 (V3)
unnamed: C20.1, U7.7 (XI), Y1.1
unnamed: C21.1, U7.8 (XO), Y1.3

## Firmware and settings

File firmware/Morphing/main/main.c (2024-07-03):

/*
MIT License

Copyright (c) 2024 Society of Robotics and Automation

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
THE SOFTWARE IS PROVIDED "AS IS", WITHOUT WARRANTY OF ANY KIND, EXPRESS OR
IMPLIED, INCLUDING BUT NOT LIMITED TO THE WARRANTIES OF MERCHANTABILITY,
FITNESS FOR A PARTICULAR PURPOSE AND NONINFRINGEMENT. IN NO EVENT SHALL THE
AUTHORS OR COPYRIGHT HOLDERS BE LIABLE FOR ANY CLAIM, DAMAGES OR OTHER
LIABILITY, WHETHER IN AN ACTION OF CONTRACT, TORT OR OTHERWISE, ARISING FROM,
OUT OF OR IN CONNECTION WITH THE SOFTWARE OR THE USE OR OTHER DEALINGS IN THE
SOFTWARE.
*/
#include "sra_board.h"
#include "tuning_websocket_server.h"

#define TAG "MORPHING"
#define DRONE_MODE 1
#define QUAD_MODE 0
#define SET_SERVO_90 83
#define MIN_PWM (40.0f) 
#define MAX_PWM (80.0f)

motor_handle_t motor1;
motor_handle_t motor2;
bool MORPH_UNLOCK = 1, MORPH_ACTIVATE, MORPHED, DEMORPHED, FLIGHT_READY;
servo_config servo_a = {
	.servo_pin = SERVO_A,
	.min_pulse_width = CONFIG_SERVO_A_MIN_PULSEWIDTH,
	.max_pulse_width = CONFIG_SERVO_A_MAX_PULSEWIDTH,
	.max_degree = CONFIG_SERVO_A_MAX_DEGREE,
};

servo_config servo_b = {
	.servo_pin = SERVO_B,
	.min_pulse_width = CONFIG_SERVO_B_MIN_PULSEWIDTH,
	.max_pulse_width = CONFIG_SERVO_B_MAX_PULSEWIDTH,
	.max_degree = CONFIG_SERVO_B_MAX_DEGREE,
};

servo_config servo_c = {
	.servo_pin = SERVO_C,
	.min_pulse_width = CONFIG_SERVO_C_MIN_PULSEWIDTH,
	.max_pulse_width = CONFIG_SERVO_C_MAX_PULSEWIDTH,
	.max_degree = CONFIG_SERVO_C_MAX_DEGREE,
};

servo_config servo_d = {
	.servo_pin = SERVO_D,
	.min_pulse_width = CONFIG_SERVO_D_MIN_PULSEWIDTH,
	.max_pulse_width = CONFIG_SERVO_D_MAX_PULSEWIDTH,
	.max_degree = CONFIG_SERVO_D_MAX_DEGREE,
};

static void mcpwm_servo_control(void *arg)
{
	ESP_ERROR_CHECK(enable_motor_driver(&motor1, MOTOR_A_0));
	ESP_ERROR_CHECK(enable_motor_driver(&motor2, MOTOR_A_1));
	ESP_ERROR_CHECK(enable_servo());
	
	while (1)
	{
		if (MORPH_UNLOCK == QUAD_MODE){
			if (DEMORPHED == false){
				ESP_LOGI(TAG, "Demorphing...\n");
				for (int i = 0; i <= SET_SERVO_90; i+=2){
					ESP_ERROR_CHECK(set_angle_servo(&servo_a, i));
					ESP_ERROR_CHECK(set_angle_servo(&servo_b, SET_SERVO_90 - i));
					ESP_ERROR_CHECK(set_angle_servo(&servo_c, i));
					ESP_ERROR_CHECK(set_angle_servo(&servo_d, SET_SERVO_90 - i));
					vTaskDelay(10);
				}
				DEMORPHED = true;
				ESP_LOGI(TAG, "QUAD MODE ACTIVATED\n");
				ESP_LOGI(TAG, "Activating wheels...\n");
			}
			else {
				if(read_comms().val_changed){
            		float speed = read_comms().speed;
            		ESP_LOGI(TAG, "speed: %f", speed);                                          //print to console
            		float motor_pwm = bound((speed), MIN_PWM, MAX_PWM);
            		if(read_comms().front){
						ESP_LOGI(TAG, "forward");
						ESP_ERROR_CHECK(set_motor_speed(motor1, MOTOR_FORWARD, motor_pwm));
						ESP_ERROR_CHECK(set_motor_speed(motor2, MOTOR_FORWARD, motor_pwm));
					} else if(read_comms().back){
						ESP_LOGI(TAG, "backward");
						ESP_ERROR_CHECK(set_motor_speed(motor1, MOTOR_BACKWARD, motor_pwm));
						ESP_ERROR_CHECK(set_motor_speed(motor2, MOTOR_BACKWARD, motor_pwm));
					} else if(read_comms().right_turn) {
						ESP_LOGI(TAG, "right turn");
						ESP_ERROR_CHECK(set_motor_speed(motor1, MOTOR_FORWARD, motor_pwm));
						ESP_ERROR_CHECK(set_motor_speed(motor2, MOTOR_BACKWARD, motor_pwm));
					}
					else if(read_comms().left_turn) {
						ESP_LOGI(TAG, "left turn");
						ESP_ERROR_CHECK(set_motor_speed(motor1, MOTOR_BACKWARD, motor_pwm));
						ESP_ERROR_CHECK(set_motor_speed(motor2, MOTOR_FORWARD, motor_pwm));
					} else {
						ESP_LOGI(TAG, "stop");
						ESP_ERROR_CHECK(set_motor_speed(motor1, MOTOR_STOP, 0));
						ESP_ERROR_CHECK(set_motor_speed(motor2, MOTOR_STOP, 0));
					}
					reset_val_changed_coms();
				}
				vTaskDelay(10 / portTICK_PERIOD_MS);
				
				if (MORPH_ACTIVATE == true){
					MORPH_UNLOCK = DRONE_MODE;
					MORPHED = false;
					vTaskDelay(50);
				}
			}
		}
		else {                                          //DRONE_MODE
			if (MORPHED == false){
				ESP_LOGI(TAG, "Morphing...\n");
				for (int i = 0; i<= SET_SERVO_90; i+=2){
					set_angle_servo(&servo_a, SET_SERVO_90 - i);
					set_angle_servo(&servo_b, i);
					set_angle_servo(&servo_c, SET_SERVO_90 - i);
					set_angle_servo(&servo_d, i);
					vTaskDelay(10);
				}
				MORPHED = true;
				ESP_LOGI(TAG, "DRONE MODE ACTIVATED\n");
			}
			else {
				ESP_LOGI(TAG, "Activating Propellers...\n");
				FLIGHT_READY = true;
				if (MORPH_ACTIVATE == true){
					MORPH_UNLOCK = QUAD_MODE;
					DEMORPHED = false;
					vTaskDelay(50);
				}
			}

		}
		// set_motor_speed(motor1, MOTOR_FORWARD, 100);
		// set_motor_speed(motor2, MOTOR_FORWARD, 100);
		// set_angle_servo(&servo_a, 0);
		// set_angle_servo(&servo_b, 83);
		// set_angle_servo(&servo_c, 83);
		// set_angle_servo(&servo_d, 0);
		// vTaskDelay(100);
#ifdef CONFIG_ENABLE_OLED
		// Diplaying Servo A, Servo B, Servo C, Servo D values on OLED
		display_servo_values(read_servo(&servo_a), read_servo(&servo_b), read_servo(&servo_c), read_servo(&servo_d));
#endif
		vTaskDelay(100);
	}
}

void app_main()
{
	start_websocket_server();
	ESP_LOGD(TAG, "Testing servo motors\n");
	xTaskCreate(mcpwm_servo_control, "mcpwm_example_servo_control", 4096, NULL, 5, NULL);
}

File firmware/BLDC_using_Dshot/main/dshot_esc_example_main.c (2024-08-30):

/*
 * SPDX-FileCopyrightText: 2021-2022 Espressif Systems (Shanghai) CO LTD
 *
 * SPDX-License-Identifier: Unlicense OR CC0-1.0
 */

#include "freertos/FreeRTOS.h"
#include "freertos/task.h"
#include "esp_log.h"
#include "driver/rmt_tx.h"
#include "dshot_esc_encoder.h"

#if CONFIG_IDF_TARGET_ESP32H2
#define DSHOT_ESC_RESOLUTION_HZ 32000000 // 32MHz resolution, DSHot protocol needs a relative high resolution
#else
#define DSHOT_ESC_RESOLUTION_HZ 40000000 // 40MHz resolution, DSHot protocol needs a relative high resolution
#endif
#define DSHOT_ESC_GPIO_NUM      15

static const char *TAG = "example";

void app_main(void)
{
    ESP_LOGI(TAG, "Create RMT TX channel");
    rmt_channel_handle_t esc_chan = NULL;
    rmt_tx_channel_config_t tx_chan_config = {
        .clk_src = RMT_CLK_SRC_DEFAULT, // select a clock that can provide needed resolution
        .gpio_num = DSHOT_ESC_GPIO_NUM,
        .mem_block_symbols = 64,
        .resolution_hz = DSHOT_ESC_RESOLUTION_HZ,
        .trans_queue_depth = 10, // set the number of transactions that can be pending in the background
    };
    ESP_ERROR_CHECK(rmt_new_tx_channel(&tx_chan_config, &esc_chan));

    ESP_LOGI(TAG, "Install Dshot ESC encoder");
    rmt_encoder_handle_t dshot_encoder = NULL;
    dshot_esc_encoder_config_t encoder_config = {
        .resolution = DSHOT_ESC_RESOLUTION_HZ,
        .baud_rate = 300000, // DSHOT300 protocol
        .post_delay_us = 50, // extra delay between each frame
    };
    ESP_ERROR_CHECK(rmt_new_dshot_esc_encoder(&encoder_config, &dshot_encoder));

    ESP_LOGI(TAG, "Enable RMT TX channel");
    ESP_ERROR_CHECK(rmt_enable(esc_chan));

    rmt_transmit_config_t tx_config = {
        .loop_count = -1, // infinite loop
    };
    dshot_esc_throttle_t throttle = {
        .throttle = 0,
        .telemetry_req = false, // telemetry is not supported in this example
    };

    ESP_LOGI(TAG, "Start ESC by sending zero throttle for a while...");
    ESP_ERROR_CHECK(rmt_transmit(esc_chan, dshot_encoder, &throttle, sizeof(throttle), &tx_config));
    vTaskDelay(pdMS_TO_TICKS(2000));

    ESP_LOGI(TAG, "Increase throttle, no telemetry");
    for (uint16_t thro = 1000; thro < 1500; thro += 20) {
        throttle.throttle = thro;
        ESP_ERROR_CHECK(rmt_transmit(esc_chan, dshot_encoder, &throttle, sizeof(throttle), &tx_config));
        // the previous loop transfer is till undergoing, we need to stop it and restart,
        // so that the new throttle can be updated on the output
        ESP_ERROR_CHECK(rmt_disable(esc_chan));
        ESP_ERROR_CHECK(rmt_enable(esc_chan));
        vTaskDelay(pdMS_TO_TICKS(1000));
    }

}

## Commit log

2024-04-19 [ Design files ] : Adds Stand for the Robot
    [Stand.SLDPRT]
2024-04-19 [ Design ] : Analysis (PASSING) with FOS 15
    [Stand.DXF, Stand.IGS, Stand.SLDPRT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]
2024-05-20 PCB files updated
    [100SP3T1B1M2QEH.step, 3296W-1-250.step, 47uH Inductor.STEP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]
2024-07-03 [UPDATE]: Adds morphing code (#5)
    * initial servo angle testing
    * Morphing Demorphing code
    * removed sra board components
    * Rewmoved sra board components
    * Added sra-board-component as submodule
    * Added sra-board-component as submodule
    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
2024-08-30 [MORPHOBOT]: Adds all the cad files (#6)
    [Bearing_Proto.SLDPRT, Chassis2.SLDPRT, Left_leg_final.SLDPRT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]
2024-08-30 Adds dshot_esc code (#7)
    * Added code for bldc using dshot-esc
    * Update README.md
2024-09-05 Adds documentation , firmware and design files in proper directory structure (#8)
    * Structuring the repo and add additional files
    * Adds documentation , organizes file structure with addition of CAD and PCB design files
    * Fixes issue with displaying images
    [100SP3T1B1M2QEH.step, 3296W-1-250.step, 47uH Inductor.STEP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]
